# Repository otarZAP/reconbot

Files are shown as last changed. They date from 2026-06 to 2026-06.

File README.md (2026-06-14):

# 🛰️ ReconBot — a tactical two-wheeled recon drone

A small, sleek two-wheeled recon drone you and your kids can build together. A single
**ESP32-S3-CAM** streams live video to a web app and drives two
wheels through an **L298N** motor driver — a fixed forward-facing camera giving
you a live first-person view as you drive.

No app to install. The bot makes its own WiFi hotspot; your phone joins it and
opens a web page. Touch-and-hold the on-screen joystick to drive.

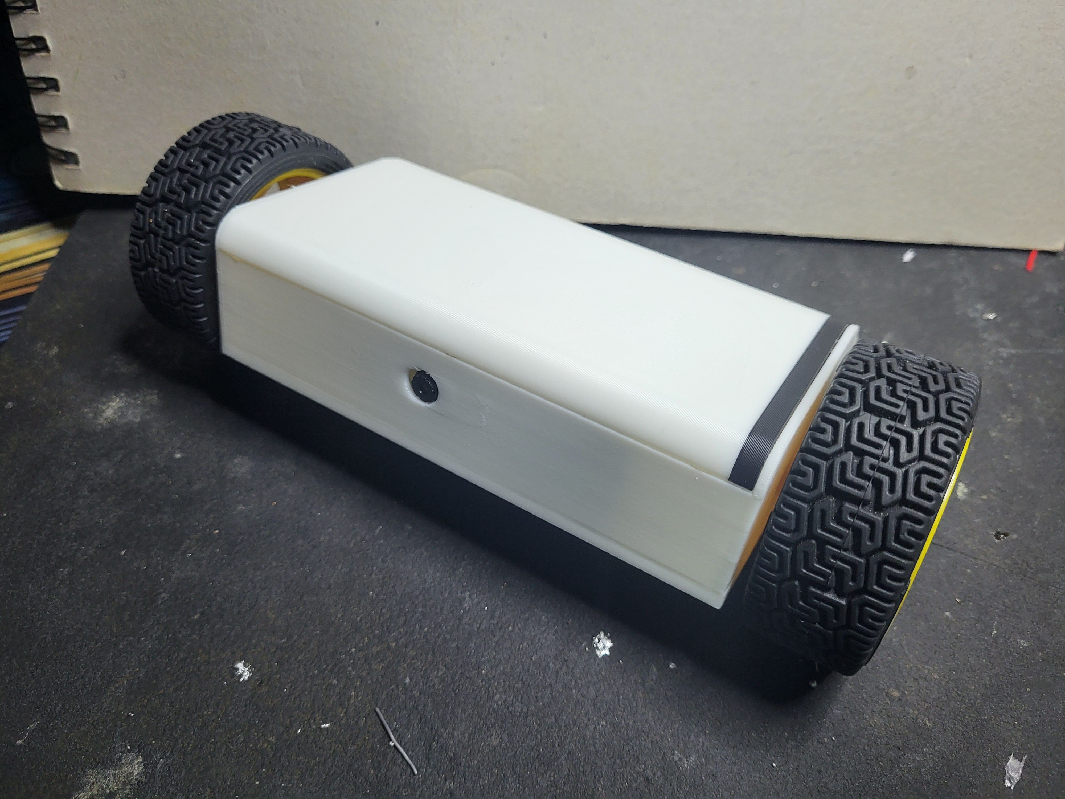
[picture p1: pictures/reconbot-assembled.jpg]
The assembled ReconBot — 3D-printed chassis and lid on car-kit wheels

*The finished drone: printed chassis + lid, riding on salvaged car-kit wheels.*

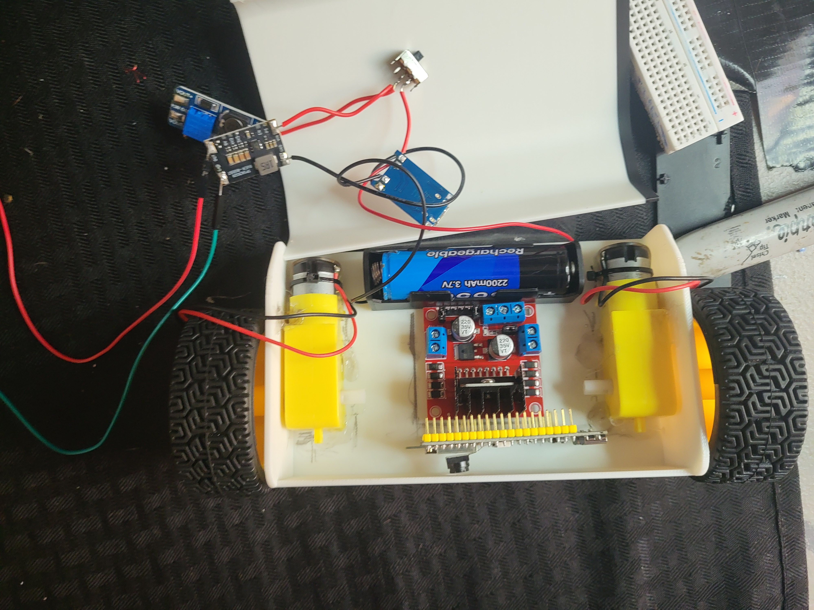
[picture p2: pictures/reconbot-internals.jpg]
Inside the chassis — motor driver, boost converter, 18650, and gear motors

*Inside: the L298N motor driver, MT3608 boost, 18650 cell, and the two gear motors.*

---

## What makes it cool

* **Coaxial-pendulum chassis** — both wheels share one axle line and the body
  hangs *below* the axle. Gravity keeps it upright, so there is **no balancing
  code to tune** — it's reliable on day one and still looks the part.
* **Live FPV camera** — a fixed forward-facing ESP32-S3-CAM streams video so you
  drive from the bot's point of view.
* **Tactical green-on-black HUD** — corner brackets, scanlines, live "LINK" status.

> We deliberately did **not** build a true Segway-style self-balancer. With
> salvaged car-kit gear motors, balancing is twitchy and frustrating to tune —
> the wrong first project. The pendulum design gives the same sleek look with
> none of the pain. See [docs/04_LEARN.md](docs/04_LEARN.md) for the physics.

---

## What you need

Most of this is common hobby-electronics stock — a lot of it can be salvaged
from an Arduino starter/car kit.

| Part | Qty | Role |
|---|---|---|
| ESP32-S3-CAM (FORIOT, OV3660) | 1 | camera + brain + WiFi + control |
| L298N dual H-bridge | 1 | drives the two wheels |
| 2× DC gear motors + wheels | 2 | drive (salvage from a toy car kit) |
| MPU-6050 IMU *(optional)* | 1 | tilt read-out on the HUD (later) |
| 18650 cell + holder | 1 | power |
| TP4056 (USB-C, protected) | 1 | charge + protect the cell |
| TPS63020 buck/boost (3.3 V) | 1 | clean power for the brain |
| MT3608 boost | 1 | 5 V for the motors |
| Rocker switch | 1 | on/off |
| Jumper wire / hookup wire | — | wiring |
| 3D-printed chassis + lid | 1 set | body (STLs included; wheels are the car-kit's) |

Full mapping + quantities: [hardware/BOM.md](hardware/BOM.md).

---

## How it's powered (quick view)

One 18650 cell, two converters — the brain and the motors are kept on
**separate power rails** so motor noise can't reset the camera (the #1 thing
that frustrates beginners).

```
18650 ─► TP4056 (charge/protect) ─► switch ─┬─ TPS63020 → 3.3V → ESP32-S3-CAM (brain)
                                            └─ MT3608   → 5.0V → L298N motor driver (muscle)
```

Full diagram + every wire: [docs/02_WIRING_GUIDE.md](docs/02_WIRING_GUIDE.md).

---

## Quick start (5 steps)

1. **Print the parts** — [hardware/3D_PRINTING.md](hardware/3D_PRINTING.md).
2. **Flash the firmware** — open [firmware/reconbot/reconbot.ino](firmware/reconbot/reconbot.ino)
   in the Arduino IDE, set the board options listed at the top of that file
   (the proven board settings — TTL port, OPI PSRAM, CDC Disabled, 115200),
   and upload.
3. **Wire it up** — follow [docs/02_WIRING_GUIDE.md](docs/02_WIRING_GUIDE.md).
4. **Connect your phone** — join WiFi **`ReconBot`** (default password
   `changeme123` — set your own in `config.h`), open Safari to
   **`http://192.168.4.1`**.
5. **Drive** — touch-hold the on-screen joystick to drive while you watch the
   live video feed.

Start to finish, step by step: [docs/01_BUILD_GUIDE.md](docs/01_BUILD_GUIDE.md).

---

## Project layout

```
reconbot/
├── README.md                  ← you are here
├── firmware/reconbot/         ← the code that runs on the ESP32-S3-CAM
│   ├── reconbot.ino           ← main program
│   ├── config.h               ← EDIT THIS: WiFi, pins, tuning
│   ├── camera_pins.h          ← camera pin map (verify vs your board)
│   └── web_index.h            ← the phone web app (HTML/CSS/JS)
├── docs/
│   ├── 01_BUILD_GUIDE.md      ← full step-by-step assembly
│   ├── 02_WIRING_GUIDE.md     ← pinouts, power tree, every connection
│   ├── 03_TROUBLESHOOTING.md  ← when something doesn't work
│   └── 04_LEARN.md            ← how it all works (the educational part)
├── hardware/
│   ├── BOM.md                 ← bill of materials
│   └── 3D_PRINTING.md         ← what to print + slicer settings
└── freecad/                   ← print-ready STLs (chassis + lid)
    ├── drone_chassis.stl
    └── drone-lid.stl
```

---

## Safety (read this with your son)

* **LiPo/Li-ion cells are not toys.** Never short the 18650, charge only on the
  TP4056, never leave charging unattended, never puncture a cell.
* **Power off (switch) before plugging in USB** to program, so two power sources
  don't fight.
* **Wheels off the ground** the first time you test motors.
* Double-check **+ and −** before switching on. Reversed power kills boards.

Have fun. 🟢

---

## License

Released under the [MIT License](LICENSE) — free to use, modify, and share.
Built as a father-and-son learning project; if you build your own, have fun
and stay safe with the battery.

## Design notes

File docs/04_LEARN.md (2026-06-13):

# 🎓 How ReconBot Works — the learning guide

The fun part: understanding *why* every piece is there. Read a section before or
after building the matching stage. Each one is short on purpose.

---

## 1. Why a "pendulum" instead of a balancing Segway?

Both have two wheels on one axle. The difference is **where the weight sits**.

* **Self-balancer (Segway):** weight is *above* the axle. That's like balancing a
  broom on your hand — it always wants to fall, so a computer must read the tilt
  (with the MPU-6050) and constantly drive the wheels to catch it. This is a
  **closed-loop control** problem solved with a **PID controller**, and it's
  genuinely hard to tune — especially with cheap gear motors that have "backlash"
  (slop in the gears) and a delay before they respond.

* **Pendulum (what we built):** weight hangs *below* the axle. That's like a
  swing or a pendulum — gravity *pulls it upright on its own*. No sensor, no
  control loop, no tuning. It's **passively stable**. It still has that sleek
  two-wheeled drone look because the wheels and body shape are the same.

> Engineering lesson: the best way to solve a hard control problem is often to
> **redesign so you don't need control at all**. Moving the battery low turned a
> PID-tuning nightmare into a part that just works. Keep the self-balancer in
> your back pocket as a *future* project once the motors and code are familiar.

The MPU-6050 still earns a spot later: we can *read* the tilt and show it on the
HUD for telemetry — using the sensor without depending on it to stay upright.

---

## 2. How the motors are controlled — H-bridge + PWM

A DC motor has two terminals. Apply voltage one way → spins forward; flip the
voltage → spins backward. To flip voltage under software control we use an
**H-bridge** — four electronic switches in an "H" shape around the motor. The
**L298N** has two H-bridges (one per motor).

* The two **direction pins** (IN1/IN2 for the left motor) pick which way current
  flows → which way the wheel turns.
* The **enable pin** (ENA) turns the bridge on/off. We don't just turn it on — we
  flick it on-and-off *thousands of times a second*. The fraction of time it's
  on is the **duty cycle**. 100% on = full speed, 50% = roughly half speed. This
  trick is **PWM (Pulse-Width Modulation)**, and it's how almost everything
  controls power smoothly: motor speed, LED brightness, even class-D audio.

In the code, `ledcWrite(pin, duty)` sets the duty (0–255). The ESP32 has
dedicated **LEDC** hardware that generates the PWM so the main program is free
to do other things (like stream video).

> Detail worth knowing: the camera *also* uses an LEDC channel for its clock.
> That's why the code uses `ledcAttachChannel(...)` to put the motor PWM on
> *different* channels — two parts sharing one hardware resource would fight.

---

## 3. How video gets to your phone — MJPEG

Video sounds complicated, but ours is simple: the camera takes a **JPEG photo**,
sends it, takes another, sends it… ~20–30 times a second. Your eye blends them
into motion. That stream of JPEGs over one HTTP connection is called **MJPEG**
(Motion JPEG). The browser's `<img>` tag knows how to keep showing the newest
frame.

It's not as efficient as "real" video (H.264), but it's **dead simple and
low-latency**, which is perfect for driving a robot where you want to see *now*,
not a smooth-but-delayed picture.

---

## 4. How the controls reach the bot — a tiny web server

The ESP32 runs a small **web server**. Two jobs, on two ports:

* **Port 80** serves the HUD web page and listens for commands like
  `/control?joy=30,-80` (steer + drive) or `/control?cmd=S` (stop).
* **Port 81** serves the MJPEG video, so a slow video frame never blocks a
  control command.

As you move the on-screen joystick, the page sends `joy=x,y` (turn, forward).
Let go and it sends `cmd=S` (stop). That's the whole protocol — plain text in a
URL. You could literally type one into a browser to drive the bot.

> No app store, no install: the bot *is* a web server, and the browser already on
> the iPhone is the client. That's the same idea that runs the whole internet.

---

## 5. The failsafe — why the bot stops itself

What if you walk out of WiFi range, or close the app, while driving? The bot
would keep going. So the page sends a quiet "ping" every 0.4 s, and the firmware
remembers the time of the **last message**. In `loop()`, if more than
`FAILSAFE_MS` (0.7 s) passes with no message, it stops the motors.

> This is a **watchdog / deadman switch** — a core safety pattern in robotics,
> cars, and industrial machines: "if I stop hearing from the controller, assume
> the worst and go safe."

---

## 6. Why two separate power supplies?

Motors are *electrically loud*. When they start, they yank current and make the
voltage dip and spike. A sensitive brain (ESP32 + camera + WiFi radio) sharing
that same wire will **brown out and reset** — the single most common beginner
frustration with ESP32-CAM robots.

So we split power into two **rails**:

* **TPS63020 → 3.3 V → brain.** It's a **buck-boost** converter: it can step
  voltage *down or up*. Even when the battery sags under motor load, it *boosts*
  back up to a steady 3.3 V. The brain never notices the motors.
* **MT3608 → 5 V → motors.** All the noisy stuff lives here.

They only meet at the battery and at **common ground**. Clean brain, happy bot.

> Why not a 2-cell pack into the TPS63020 for more motor power? Because that part
> accepts **max 5.5 V in** — a single Li-ion cell only. Datasheets matter: one
> overlooked number can release the magic smoke. 🔌💨

---

## 7. The whole signal flow, one picture

```
   your thumb            iPhone (Safari)             ESP32-S3-CAM                 the world
  ───────────  touch  ─────────────────  WiFi  ──────────────────────────────  ──────────
   hold ▲      ─────►  send /control?cmd=F ───►  web server (port 80)
                                                    │
                                                    ├─► set motor pins + PWM ─►  L298N ─► wheels turn
   camera   ◄──────── <img> shows JPEGs ◄───── MJPEG stream (port 81) ◄── camera takes photos
                          (every 0.4s: ping ───► resets the failsafe timer)
```

That's the entire robot. Five small ideas — H-bridge, PWM, MJPEG, a web server,
and a watchdog — wired together. Once these click, you can build almost any
connected robot. 🟢

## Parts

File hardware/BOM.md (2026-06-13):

# 📦 Bill of Materials

Most of these are common hobby-electronics parts, and several can be salvaged
from an Arduino starter/car kit. You shouldn't need anything exotic.

## Core build (required)

| # | Part | Qty | Role |
|---|---|----:|---|
| 1 | **ESP32-S3-CAM (FORIOT, OV3660, N16R8)** | 1 | Camera + brain + WiFi + control |
| 2 | **L298N dual H-bridge module** | 1 | Drives both wheels |
| 3 | **DC gear motors + wheels** | 2 | Drive — salvage from a toy/Arduino car kit |
| 4 | **18650 Li-ion cell** | 1 | Main battery |
| 5 | **18650 holder (single, wire leads)** | 1 | Holds the cell |
| 6 | **TP4056 Type-C charger w/ protection** | 1 | Charge + protect the cell |
| 7 | **TPS63020 / XL63020 buck-boost (3.3 V)** | 1 | Clean 3.3 V for the brain |
| 8 | **MT3608 boost converter** | 1 | 5 V for the motors |
| 9 | **Rocker switch (SPST)** | 1 | Master on/off |
| 10 | **Hookup wire / jumper wires** | — | Wiring |
| 11 | **Heatshrink, solder** | — | Tidy, durable joints |
| 12 | **3D-printed chassis + lid** | 1 set | Body + top cover (STLs included; wheels come from the car kit) |

> **Battery note:** use a good **18650** cell for the bot. Avoid tiny 1S LiPos
> (e.g. 450 mAh) — they're too small to drive the motors well. Only charge the
> cell on the TP4056, and never leave it charging unattended.

## Optional / later add-ons

| Part | Adds |
|---|---|
| **MPU-6050 IMU** | Live tilt/heading on the HUD (`USE_IMU 1`) |
| **DFPlayer Mini + 3 W speaker** | Startup chirp / "drone deployed" voice |
| **SSD1306 OLED 0.96"** | Tiny on-board status display |
| **LED** | Headlight on a spare GPIO |
| **NEO-6M GPS** | Outdoor position logging |
| **Spare ESP32-S3 devkit (e.g. XIAO ESP32-S3)** | Second brain / experiments |

## Tools

Soldering iron + solder + heatshrink · flush cutters · digital calipers ·
multimeter · breadboard + jumpers (for bench-testing power) ·
a 3D printer + PLA/PETG filament.

---

### A note on quantities
This is a forgiving first build. The ESP32-S3-CAM and the support parts are
cheap, so it's worth having a spare or two on hand — you can build more than one
drone and not stress about releasing a little magic smoke while you learn.

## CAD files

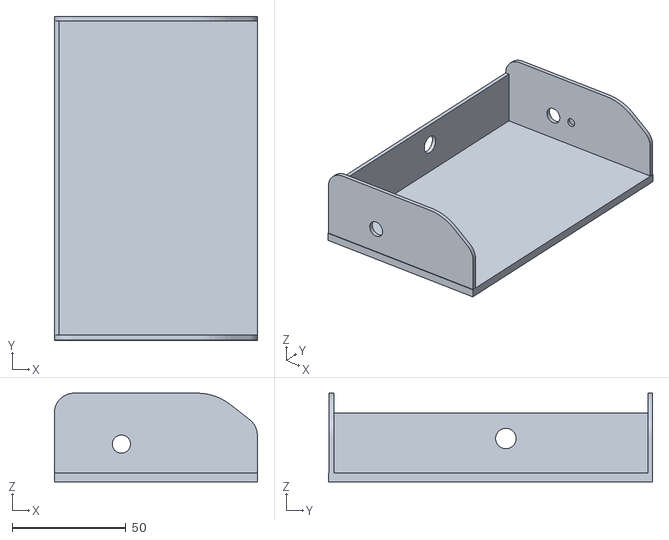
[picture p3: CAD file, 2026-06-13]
freecad/drone_chassis.stl
89.6 x 142.7 x 39.1

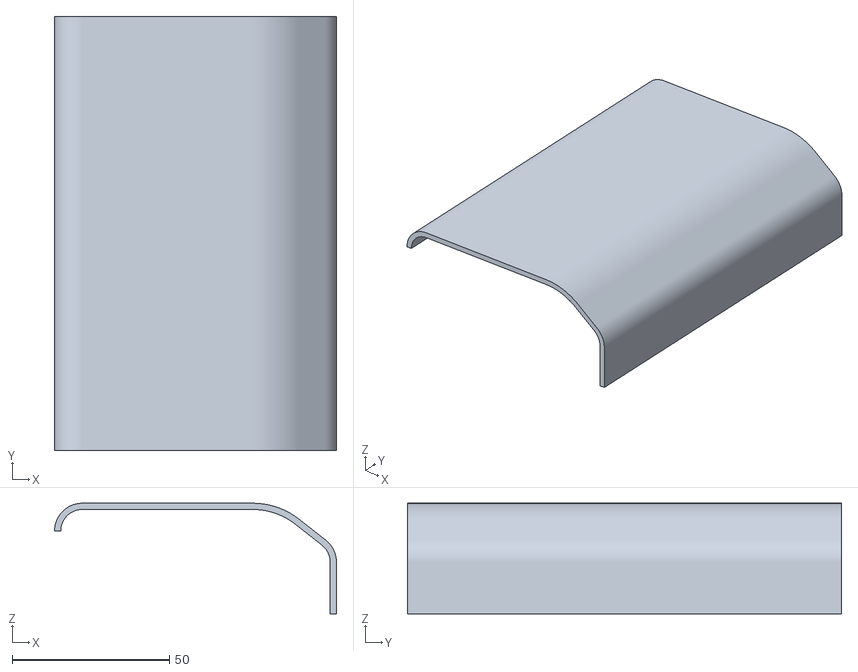
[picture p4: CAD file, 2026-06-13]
freecad/drone-lid.stl
89.6 x 138.0 x 35.1

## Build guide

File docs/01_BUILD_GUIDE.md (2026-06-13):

# 🛠️ ReconBot Build Guide

A staged build. Each stage **ends in a test** — don't move on until the test
passes. This is the secret to "smooth sailing": you never debug ten things at
once, only the one thing you just added.

**Time:** ~a weekend, split into sessions. Great pace for building with a teen.

**Tools you have:** soldering iron + heatshrink, flush cutters, calipers,
multimeter (from the ELEGOO kit / power supply), the P1S printer.

---

## Stage 0 — Set up the computer (30 min)

1. Install the **Arduino IDE 2.x** (free, arduino.cc).
2. Add ESP32 support: **File ▸ Preferences ▸ Additional Boards Manager URLs**,
   paste:
   `https://raw.githubusercontent.com/espressif/arduino-esp32/gh-pages/package_esp32_index.json`
3. **Tools ▸ Board ▸ Boards Manager**, search **esp32**, install **"esp32" by
   Espressif Systems** (v3.0 or newer).
4. Plug the ESP32-S3-CAM into the computer using the **USB-C port labelled
   "TTL"** (the CH340C port). The **OTG** port is *not* for flashing. A COM port
   should appear under **Tools ▸ Port**.

✅ **Test:** the board appears as a COM port. (No code yet.)

> If you've flashed an ESP32-S3-CAM before, the BOOT/RST dance below will be
> familiar — same procedure applies here.

---

## Stage 1 — Flash the ReconBot firmware (15 min)

The camera pin map is **already confirmed** (taken from the FORIOT board's
silkscreen pinout and verified on hardware), so we skip straight to the firmware.

1. Open [`firmware/reconbot/reconbot.ino`](../firmware/reconbot/reconbot.ino).
   The folder also has `config.h`, `camera_pins.h`, `web_index.h` — keep all
   four together; the IDE opens them as tabs.
2. In **`config.h`**, set your hotspot password (`AP_PASS`) to something you'll
   remember. Leave everything else at defaults for now.
3. Set **Tools** to these proven settings:
   * Board: **ESP32S3 Dev Module**
   * PSRAM: **OPI PSRAM**  ← mandatory; camera won't init without it
   * Flash Size: **16MB (128Mb)**
   * Partition Scheme: **16M Flash (3MB APP/9.9MB FATFS)** (or **Huge APP**)
   * USB CDC On Boot: **Disabled**
   * Upload Speed: **115200**  (lower = more reliable on the CH340)
4. **Enter download mode:** hold **BOOT**, tap **RST**,
   release **BOOT**, then click **Upload** immediately.
5. Open **Tools ▸ Serial Monitor** at **115200**. You should see:
   `AP up. Join WiFi 'ReconBot', then open http://192.168.4.1`.
6. On your iPhone: **Settings ▸ WiFi ▸ ReconBot**, enter the password. Then open
   **Safari ▸ `http://192.168.4.1`**.

✅ **Test:** the green tactical HUD loads on your phone with live video. (No
motors yet — the D-pad does nothing because the L298N isn't wired. That's fine.)

> Upload won't connect? It's almost always the wrong USB-C port (use TTL), the
> upload speed, or the BOOT/RST timing — see
> [03_TROUBLESHOOTING.md](03_TROUBLESHOOTING.md). iPhone may warn "no internet"
> on the ReconBot network — expected; stay connected anyway. WiFi is 2.4 GHz.

> **Optional confidence check:** if you'd rather prove the camera before our
> code, flash **File ▸ Examples ▸ ESP32 ▸ Camera ▸ CameraWebServer** (model
> `CAMERA_MODEL_ESP32S3_EYE`) first — but since the pin map already matches your
> working cameras, you can skip this.

---

## Stage 2 — Print the parts (print while you build)

Start these prints now; they run in the background. Settings + the sleek,
compact pendulum design are in [hardware/3D_PRINTING.md](../hardware/3D_PRINTING.md).

You'll print just two parts — the included STLs: the **chassis** (the main body;
it holds the ESP32 + L298N + battery, mounts the motors, and *hangs below the
axle*) and a **lid** that closes the top. The **wheels come from the car kit**,
not the printer.

✅ **Test:** the chassis comes off the plate clean; the ESP32 and L298N sit in
their slots and the 18650 drops into the bottom.

---

## Stage 3 — Build & test the power tree (45 min)

Follow [02_WIRING_GUIDE.md](02_WIRING_GUIDE.md) §1. Build power **on the
breadboard first**, not soldered to the bot.

1. 18650 → TP4056 (**B+/B−**). Bot power comes from TP4056 **OUT+/OUT−**.
2. Add the **switch** in the OUT+ line.
3. Wire the **TPS63020** input to the switched rail. Switch on. Measure its
   output: **3.3 V**. Switch off.
4. Wire the **MT3608** input to the switched rail. Switch on. Adjust its pot to
   **5.0 V** on the output. Switch off.

✅ **Test:** multimeter reads 3.3 V and 5.0 V on the two rails, and nothing gets
warm. Don't connect any boards until both rails are confirmed.

---

## Stage 4 — Wire & test the motors (45 min)

1. **Switch off / USB unplugged.** Wire ESP32 → L298N per
   [02_WIRING_GUIDE.md](02_WIRING_GUIDE.md) §2 (the 6 signal pins + GND).
2. Remove the **ENA/ENB jumpers** and the **+5V regulator jumper** on the L298N.
3. Feed L298N **+12V (VS)** and **+5V** from the 5 V rail; connect **GND**.
4. Connect the two motors to OUT1/2 and OUT3/4. **Keep wheels off the ground.**
5. Power the brain from the 3.3 V rail (3V3 + GND). Switch on.
6. Connect the phone, open the HUD, and press the D-pad.

✅ **Test:** push the joystick forward and both wheels spin the same way (the way
that would move the bot forward). Push left/right to check steering. The further
you push the stick, the faster it goes — there's no separate speed slider.

* A wheel spins backward? Swap that motor's two output wires, **or** set
  `INVERT_LEFT`/`INVERT_RIGHT` in `config.h` and re-upload.
* Camera resets when motors start? Your rails aren't separate — recheck that the
  brain is on the **TPS63020** rail, not the motor rail. (See Troubleshooting.)

> Notice the **failsafe**: let go of the D-pad and the wheels stop. Close the
> app and within ~0.7 s the bot stops itself.

---

## Stage 5 — Mechanical assembly (the pendulum chassis) (1–2 hr)

This is what gives it its distinctive look. The key idea: **the two motors mount on a
single axle line, and the chassis hangs below them.** Low weight = naturally
upright.

1. **Mount the motors** in the chassis so both output shafts are **coaxial**
   (pointing left and right along one straight line).
2. **Press the car-kit wheels** onto the shafts.
3. The **chassis hangs below** the shaft line so its mass sits *below* the axle.
   Put the **heaviest item (the 18650) at the very bottom** — the lower the
   battery, the more stable and upright it sits.
4. **Mount the camera** on the front of the chassis, facing forward. It's
   **fixed** (no tilt) — aim it roughly level so you can see where you're driving.
5. Route wires neatly and secure them with a little tape or zip-ties, then
   **clip the lid on** top.

✅ **Test (the magic moment):** set it on the floor, hands off. It should sit
upright on its two wheels, body hanging below the axle. A gentle
nudge and it rocks back upright.

> If it won't stay upright: move the battery **lower**, and make sure the body's
> center of mass is **below** the axle, not level with it. If it spins around the
> axle hard when you hit Forward, push the stick more gently, lower
> **`DEFAULT_SPEED`** in `config.h`, and/or raise **`JOY_EXPO`** for a softer
> throttle — gentle starts keep the body from swinging.

---

## Stage 6 — First drive & tuning (ongoing fun)

* Start **gently**. The pendulum body will bob when you accelerate — that's
  authentic and expected. Smooth, gentle throttle looks best.
* Tune the *feel* in `config.h`: `DEFAULT_SPEED`, `TURN_SPEED_SCALE`,
  `JOY_EXPO`. Re-upload to try changes.

### Ideas to grow it (great next lessons)

* Turn on the **MPU-6050** (`USE_IMU 1`) and show live tilt on the HUD.
* Add a **headlight LED** on a spare GPIO with a button on the HUD.
* Add sound with a **DFPlayer Mini + speaker** (you have both) — a startup chirp
  or "drone deployed" voice line.
* Try **`WIFI_MODE_STA`** so it joins home WiFi and you drive from any room.

See the physics and the "why" behind every choice in
[04_LEARN.md](04_LEARN.md).

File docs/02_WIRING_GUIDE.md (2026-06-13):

# 🔌 ReconBot Wiring Guide

Every wire, every pin. Wire with the **battery removed and the power switch
OFF**. Work slowly and check each connection against the tables before you
apply power.

> **Camera pins + flash settings are confirmed** from the FORIOT
> ESP32-S3-CAM's silkscreen pinout — no guessing there. The **motor GPIOs**
> below are a sound default chosen to dodge the camera, flash/PSRAM, USB,
> serial, and boot pins. If one isn't broken out on a header pad on your board,
> pick another free pin (good spares: 21, 48, 1, 2) and change it in
> [`config.h`](../firmware/reconbot/config.h) — that's the only place to edit.
> Check your board's silkscreen / pinout diagram to confirm which pads are
> broken out.

---

## 1. The power tree (build this first, test it before anything else)

One 18650 cell. The brain and the muscle live on **separate rails** on purpose:
motors create electrical noise and voltage dips, and if the camera shared that
rail it would constantly reset. The TPS63020 also *boosts* — so even when the
cell sags under motor load, the brain still gets a steady 3.3 V.

```
                       ┌─────────────────────────────────────────────┐
                       │                                             │
  [18650 +]──► TP4056 OUT+ ──► [SWITCH] ──┬──► TPS63020 IN+ ──► OUT 3.3V ──► ESP32-S3-CAM  3V3
  [18650 -]──► TP4056 OUT- ───────────────┤    TPS63020 IN- ──► OUT GND  ──► ESP32-S3-CAM  GND
                                          │
                                          ├──► MT3608 IN+ ──► OUT 5V ──┬──► L298N  +12V (VS)
                                          │    MT3608 IN- ──► OUT GND  └──► L298N  +5V  (logic, jumper OFF)
                                          │
                                          └────────────────── COMMON GROUND ──────────────────┐
                                                                                               │
   ALL grounds tie together:  18650- / TP4056 OUT- / TPS63020 GND / MT3608 GND /              │
   L298N GND / ESP32 GND ──────────────────────────────────────────────────────────────────────┘
```

**Set the converter voltages with a multimeter BEFORE connecting any board:**

* **TP4056** — battery goes on **B+ / B−**; the bot draws from **OUT+ / OUT−**.
  Charge any time via the TP4056's USB-C. (Protected version — good.)
* **TPS63020 (XL63020)** — fixed **3.3 V** out. Confirm it reads ~3.3 V.
* **MT3608** — turn its trim-pot until the output reads **5.0 V**. Do this with
  nothing connected to the output yet. (Want peppier motors later? 6 V is fine.)

> ⚠️ **Never feed more than 5.5 V into the TPS63020** — it's a single-cell part.
> That's why we power the brain straight from the one cell, not from a 2-cell pack.

> ⚠️ **Power switch OFF before connecting USB** to the ESP32 for programming.
> Otherwise USB-5V and the 3.3 V rail both try to power the board and fight.

---

## 2. ESP32-S3-CAM → L298N (motor driver)

The ESP32 sends 6 logic signals to the L298N: 2 direction + 1 speed (PWM) per motor.

| ESP32-S3 pin | → L298N pin | Meaning |
|---|---|---|
| GPIO **42** | IN1 | Left motor direction A |
| GPIO **41** | IN2 | Left motor direction B |
| GPIO **40** | ENA | Left motor speed (PWM) |
| GPIO **39** | IN3 | Right motor direction A |
| GPIO **38** | IN4 | Right motor direction B |
| GPIO **47** | ENB | Right motor speed (PWM) |
| **GND** | GND | shared ground (also in the power tree) |

> **ENA/ENB jumpers:** the L298N ships with little jumpers on ENA/ENB that force
> full speed. **Remove both jumpers** so our PWM speed control works.

> **The "+5V logic" jumper:** there's a jumper near the +5V terminal that
> enables the on-board 5 V regulator. Since we feed 5 V in from the MT3608,
> **remove that jumper** and feed the **+5V** terminal from the 5 V rail instead.

> **microSD note:** GPIO 38/39/40 are the FORIOT board's microSD slot pins
> (confirmed from the FORIOT pinout). We borrow them for motors, so
> **leave the microSD slot empty** for this build.

### L298N → motors

| L298N output | → wire | Motor |
|---|---|---|
| OUT1 / OUT2 | the two leads | **Left** gear motor |
| OUT3 / OUT4 | the two leads | **Right** gear motor |

Polarity doesn't matter yet — if a wheel spins the wrong way during testing,
either swap that motor's two wires **or** flip `INVERT_LEFT` / `INVERT_RIGHT`
in `config.h`. No re-soldering needed.

---

## 3. (Optional, later) MPU-6050 IMU

Skip this for the first build. When you want a live tilt/heading read-out on the
HUD, set `USE_IMU 1` in `config.h` and wire:

| MPU-6050 | → ESP32-S3 |
|---|---|
| VCC | 3.3 V |
| GND | GND |
| SDA | GPIO **1** |
| SCL | GPIO **2** |

(This is a *second* I²C bus, separate from the camera's internal one.)

---

## 4. Pre-power checklist

Before the very first switch-on:

- [ ] **+ and −** correct at every module (look twice).
- [ ] TPS63020 output reads **3.3 V**, MT3608 output reads **5.0 V** (measured, loaded later).
- [ ] **All grounds connected together** (brain, motors, converters, battery).
- [ ] ENA/ENB jumpers **removed**; L298N +5V regulator jumper **removed**.
- [ ] microSD slot **empty**.
- [ ] Wheels **off the ground**.
- [ ] USB **unplugged** (or switch off) so power sources don't fight.

First switch-on: the ESP32's small LED should light, and within ~5 s the
`ReconBot` WiFi network should appear on your phone. If anything smells hot or a
chip gets warm fast — **switch off immediately** and recheck polarity.

---

## Pin reference (one-page summary)

```
ESP32-S3-CAM
 ├─ 3V3  ◄── TPS63020 3.3V        (brain power)
 ├─ GND  ──  common ground
 ├─ G42 ──► L298N IN1   (L dir)
 ├─ G41 ──► L298N IN2   (L dir)
 ├─ G40 ──► L298N ENA   (L speed/PWM)
 ├─ G39 ──► L298N IN3   (R dir)
 ├─ G38 ──► L298N IN4   (R dir)
 └─ G47 ──► L298N ENB   (R speed/PWM)

L298N
 ├─ +12V (VS) ◄── 5V rail (MT3608)
 ├─ +5V       ◄── 5V rail (MT3608)   [regulator jumper OFF]
 ├─ GND       ──  common ground
 ├─ OUT1/OUT2 ──► Left motor
 └─ OUT3/OUT4 ──► Right motor
```

Next: assemble it all in [01_BUILD_GUIDE.md](01_BUILD_GUIDE.md).

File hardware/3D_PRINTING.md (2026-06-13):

# 🖨️ 3D Printing Guide

Two ready-to-print parts are included as STLs — no CAD needed to build:

* [`freecad/drone_chassis.stl`](../freecad/drone_chassis.stl) — the main body
* [`freecad/drone-lid.stl`](../freecad/drone-lid.stl) — the top cover

Drop them into your slicer and print. (The editable FreeCAD source isn't bundled
in this repo — export fresh STLs from your own model if you want to change the
geometry.)

> The **wheels are not printed** — they come from the salvaged car kit (see the
> [BOM](BOM.md)). The printed parts are just the body and its lid.

---

## What you'll print

| Part | File | Qty | Notes |
|---|---|----:|---|
| **Chassis** | `drone_chassis.stl` | 1 | Main body — holds the motors, electronics, and 18650; hangs below the axle so the mass sits low. |
| **Lid** | `drone-lid.stl` | 1 | Closes the top of the chassis and protects the electronics. |

Total filament: small — a couple of hours, well under one spool.

---

## Step 1 — Slice & print (Bambu Studio / any slicer)

| Setting | Chassis & lid |
|---|---|
| Material | **PLA** (PETG if you want it tougher) |
| Layer height | 0.20 mm |
| Walls | 3 |
| Infill | 20–30 % |
| Supports | **Yes** for overhangs / the front camera window |
| Brim | optional (helps on small contact areas) |

> If your salvaged motors or boards are a different size than the model expects,
> the parts may not fit. In that case you'll need to tweak and re-export from
> your own CAD — start press-fit clearances around 0.25 mm (too tight → raise
> toward 0.35 mm; too loose → lower it).

## Step 2 — Test the fits before assembly

* Motors, the ESP32-S3-CAM, the L298N, and the 18650 should all sit in the
  **chassis** with the **battery lowest** (that low mass is what keeps the
  pendulum upright).
* The camera fixes to the front of the chassis, facing forward — see the
  [build guide](../docs/01_BUILD_GUIDE.md).
* The **lid** should close over the top without crushing wires. Route cables
  first, then clip it on.
* **Car-kit wheels:** for more grip on smooth floors, wrap each tyre with a
  slice of silicone tape or a wide rubber band.

---

## Design intent (so you can restyle it)

The whole point of the shape is **low center of mass**: the chassis hangs
*below* the axle and the heavy 18650 lives at the bottom. That's what makes the
pendulum sit upright with no balancing code (see
[../docs/04_LEARN.md](../docs/04_LEARN.md) §1).

Want it to look more rugged/tactical? Things you can change in your own model:

* Add a faceted/angular shell around the body.
* Print a thin top "cage" so it reads as a rugged little recon unit.

Keep the **mass low and centered** and you can style the rest however you like.

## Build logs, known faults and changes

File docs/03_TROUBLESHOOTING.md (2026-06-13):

# 🚑 ReconBot Troubleshooting

Work top-down: most problems are power or pins. Use the multimeter — guessing
wastes time.

---

## Uploading / board

**No COM port appears.**
* Use the **TTL** USB-C port (CH340C), **not** the OTG port.
* Try a different USB **cable** (many are charge-only with no data wires).

**Upload fails: "Failed to connect… No serial data received."** In order of
likelihood:
1. **Wrong port.** Use TTL, not OTG.
2. **Upload Speed too high.** Drop to **115200**.
3. **Bad cable.** Must be a data cable. Swap and test.
4. **Wrong button sequence.** Hold **BOOT** → tap **RST** → release **BOOT** →
   click Upload. Don't touch the buttons again.
5. **Battery rail on.** The power switch must be **OFF** while programming.
6. **Flaky BOOT button bypass:** short **GPIO0 to GND** with a wire while
   tapping RST, then release the wire.
7. **Dead BOOT button** (worked once, never again): the board is mechanically
   faulty — swap it. (You can't brick the chip; the ROM bootloader is permanent.)

**Compile error about `ledcAttach` / camera functions.**
* You're on an old core. Update **esp32 by Espressif** to **v3.0+** in Boards
  Manager. The v3.x LEDC API (`ledcAttach`) and these camera calls need it.

---

## Camera

**`CAMERA INIT FAILED 0x…` on the serial monitor.**
* **PSRAM** must be set to **OPI PSRAM** (Tools menu). This is almost always the
  cause — the camera won't init without OPI PSRAM.
* The pin map in `camera_pins.h` is taken from the FORIOT silkscreen pinout, so
  it usually isn't the pins. It's the PSRAM setting or a bad board.

**Video is upside-down or mirrored.**
* In `reconbot.ino`, in `cameraBegin()`, change `set_vflip` / `set_hmirror`
  (1 ↔ 0).

**HUD loads but video box stays black / "connecting".**
* The video lives on **port 81**. Some networks block it, but on the bot's own
  hotspot it's fine. Reload the page. The HUD auto-retries every second.
* Camera init may have failed — check the serial monitor (the bot still serves
  the page and drives even if the camera didn't start).

---

## Power (most "weird" problems live here)

**Camera/brain resets every time the motors move.**
* Classic shared-rail noise. The brain **must** be on the **TPS63020 3.3 V**
  rail, the motors on the **MT3608 5 V** rail — fed straight from the cell, not
  from each other. Recheck the power tree.
* Make sure **all grounds are tied together**.

**Nothing powers on.**
* Is the **switch** on? Battery charged? Measure TP4056 **OUT+** to **OUT−** —
  should be ~3.0–4.2 V.
* Measure the **two converter outputs** (3.3 V and 5.0 V). If a converter reads
  0 V, recheck its IN+ / IN− and that it's getting battery voltage.

**A module or chip gets hot fast.**
* **Switch off immediately.** Almost always reversed **+/−** on that module.
  Recheck polarity before powering again.

**TPS63020 died / outputs garbage.**
* It's a single-cell part (**max 5.5 V in**). If you fed it a 2-cell pack it's
  damaged. Use one of your spares and feed it from the single cell only.

---

## Motors

**D-pad does nothing.**
* ENA/ENB **jumpers removed**? With them on, sometimes; with our PWM they must be
  off — but also confirm the 6 signal wires match the table in the Wiring Guide.
* Is the L298N getting **+12V (VS)** *and* **+5V** *and* **GND**?
* Are the motors connected to OUT1/2 and OUT3/4?

**One wheel spins the wrong way.**
* Swap that motor's two output wires, **or** flip `INVERT_LEFT` /
  `INVERT_RIGHT` in `config.h` and re-upload.

**Motors weak / stall.**
* Raise the **MT3608** output toward 6 V (re-measure).
* Raise `DEFAULT_SPEED` in `config.h`.
* Cheap gear motors have a minimum speed — values below ~80 may just buzz; the
  HUD slider already starts at 80.

**Both wheels run only at full speed regardless of slider.**
* The **ENA/ENB jumpers are still on**. Remove them.

---

## Driving feel (pendulum chassis)

**Body swings hard / spins around the axle on launch.**
* Ease off the throttle (push the joystick less) or lower **`DEFAULT_SPEED`** in
  `config.h` — gentle throttle keeps the body from lurching.
* Move the **battery lower** in the chassis (lower center of mass = steadier).

**Won't stay upright at rest.**
* Center of mass must be **below** the axle. Add the battery at the very bottom
  of the pod; remove top-heavy items.

---

## Connection

**Phone can't find the `ReconBot` WiFi.**
* Give it ~5 s after power-on. Check the serial monitor printed `AP up`.
* Forget/re-join the network on the phone.

**Connected but `192.168.4.1` won't load.**
* Make sure you're on the **ReconBot** network (not your home WiFi). Ignore the
  "no internet" warning — that's normal.
* Type the full `http://192.168.4.1` (not https).

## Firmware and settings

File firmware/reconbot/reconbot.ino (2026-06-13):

// ===========================================================================
//  ReconBot  —  ESP32-S3-CAM recon drone firmware
// ---------------------------------------------------------------------------
//  ONE ESP32-S3-CAM does everything:
//    * streams live video to your phone (MJPEG, port 81)
//    * serves the control web app (port 80)
//    * drives two motors through an L298N (virtual-joystick steering)
//    * smooth soft-start ramping so starts/stops/turns aren't jerky
//    * drives at 640x480; HD button bumps resolution as the signal allows
//    * stops itself if the phone disconnects (failsafe)
//
//  Edit pins / WiFi / tuning in  config.h  — not here.
//  Camera pins live in  camera_pins.h.  Web app lives in  web_index.h.
//
//  Board settings in Arduino IDE (Tools menu) — these are the SAME settings
//  proven on the FORIOT ESP32-S3-CAM (N16R8):
//    Board:            "ESP32S3 Dev Module"
//    PSRAM:            "OPI PSRAM"        <-- MANDATORY; camera won't init without it
//    Flash Size:       "16MB (128Mb)"
//    Partition Scheme: "16M Flash (3MB APP/9.9MB FATFS)"  (or "Huge APP")
//    USB CDC On Boot:  "Disabled"         <-- we use UART0 over the CH340 "TTL" port
//    Upload Speed:     "115200"           <-- lower = more reliable on the CH340
//  Plug into the USB-C port labelled TTL (CH340C), NOT the OTG port.
//  To upload: hold BOOT, tap RST, release BOOT, then click Upload.
//  Needs the ESP32 board package v3.x (Boards Manager -> "esp32" by Espressif).
//  No extra libraries to install — everything used here ships with the core.
// ===========================================================================
#include "esp_camera.h"
#include <WiFi.h>
#include "esp_wifi.h"          // for the connected-phone signal strength (RSSI)
#include "esp_http_server.h"
#include "esp_timer.h"

#include "config.h"
#include "camera_pins.h"
#include "web_index.h"

#if USE_IMU
  #include <Wire.h>
#endif

httpd_handle_t control_httpd = NULL;   // port 80: web app + commands
httpd_handle_t stream_httpd  = NULL;   // port 81: video

volatile uint32_t g_lastCmdMs = 0;     // when we last heard from the phone
int  g_speed   = DEFAULT_SPEED;        // 0..255 (top speed; joystick scales within)
int  g_trim    = 0;                    // -100..100 steering trim (drive-straight tuning)
bool g_moving  = false;                // are we commanding any wheel movement?

// Virtual-joystick input, normalised to -100..100 (x = turn, y = forward).
int  g_jx = 0, g_jy = 0;

// Soft-start ramping: we move the CURRENT wheel duties toward the TARGET duties
// a little each loop tick (signed, -255..255; sign = direction).
int  g_tgtL = 0, g_tgtR = 0;
int  g_curL = 0, g_curR = 0;

volatile bool g_dancing = false;       // true while the DANCE routine owns the motors

// Camera resolution state (see config.h section 6)
bool        g_psram    = false;              // true if PSRAM present -> hi-res allowed
bool        g_hires    = false;              // HD button state
framesize_t g_curFrame = DRIVE_FRAMESIZE;    // resolution the sensor is at right now

// ---------------------------------------------------------------------------
//  MOTORS
// ---------------------------------------------------------------------------
void motorsBegin() {
  pinMode(MOTOR_A_IN1, OUTPUT);
  pinMode(MOTOR_A_IN2, OUTPUT);
  pinMode(MOTOR_B_IN3, OUTPUT);
  pinMode(MOTOR_B_IN4, OUTPUT);
  // Hardware PWM on the enable pins (auto-allocated from the bottom timers;
  // the camera sits on the top timer/channel so there's no clash).
  ledcAttach(MOTOR_A_PWM, PWM_FREQ, PWM_RES_BITS);
  ledcAttach(MOTOR_B_PWM, PWM_FREQ, PWM_RES_BITS);
  ledcWrite(MOTOR_A_PWM, 0);
  ledcWrite(MOTOR_B_PWM, 0);
}

// dir: +1 forward, -1 backward, 0 coast.  duty: 0..255
void setLeft(int dir, int duty) {
  if (INVERT_LEFT) dir = -dir;
  digitalWrite(MOTOR_A_IN1, dir > 0);
  digitalWrite(MOTOR_A_IN2, dir < 0);
  ledcWrite(MOTOR_A_PWM, dir == 0 ? 0 : duty);
}
void setRight(int dir, int duty) {
  if (INVERT_RIGHT) dir = -dir;
  digitalWrite(MOTOR_B_IN3, dir > 0);
  digitalWrite(MOTOR_B_IN4, dir < 0);
  ledcWrite(MOTOR_B_PWM, dir == 0 ? 0 : duty);
}

// Push a SIGNED duty (-255..255) to one wheel: sign picks direction, |value| the speed.
void applyWheel(bool left, int v) {
  int dir  = (v > 0) ? 1 : (v < 0 ? -1 : 0);
  int duty = abs(v);
  if (left) setLeft(dir, duty); else setRight(dir, duty);
}

// Hard stop + full reset so a ramp can't sneak the wheels back on.
void motorsStop() {
  g_jx = g_jy = 0;
  g_tgtL = g_tgtR = 0;
  g_curL = g_curR = 0;
  g_moving = false;
  applyWheel(true, 0);
  applyWheel(false, 0);
}

// Set where the wheels SHOULD end up; the loop ramps them there smoothly.
void setTargets(int left, int right) {
  g_tgtL = constrain(left,  -255, 255);
  g_tgtR = constrain(right, -255, 255);
  g_moving = (g_tgtL != 0 || g_tgtR != 0);
}

// Arcade mixing: turn the joystick (forward y + turn x) into left/right wheel
// targets, scaled by g_speed (DEFAULT_SPEED), with steering trim folded in.
void mixDrive() {
  int turn  = (g_jx * TURN_SPEED_SCALE) / 100;     // gentle, aim-able steering
  int left  = ((g_jy + turn) * g_speed) / 100;
  int right = ((g_jy - turn) * g_speed) / 100;
  // Trim eases ONE wheel a touch so the bot tracks straight (same idea as before).
  if (g_trim > 0)      right = (right * (100 - g_trim)) / 100;
  else if (g_trim < 0) left  = (left  * (100 + g_trim)) / 100;
  setTargets(left, right);
}

// Shape a raw axis (-100..100): dead-zone near centre, then an expo curve so a
// small push gives a small move while full deflection still reaches full speed.
//   out = (1-e)*x  +  e*x^3   (classic RC expo), all in integer math.
int shapeAxis(int v) {
  v = constrain(v, -100, 100);
  if (v > -JOY_DEADZONE && v < JOY_DEADZONE) return 0;
  long lin = ((long)(100 - JOY_EXPO) * v) / 100;
  long cub = ((long)JOY_EXPO * v * v * v) / 1000000L;   // x^3 scaled back to ±100
  return (int)(lin + cub);
}

void applyJoystick(int x, int y) {
  g_jx = shapeAxis(x);
  g_jy = shapeAxis(y);
  mixDrive();
}

// Move a value toward a goal by at most 'step' (the heart of the soft-start).
int stepToward(int cur, int goal, int step) {
  if (cur < goal) return min(cur + step, goal);
  if (cur > goal) return max(cur - step, goal);
  return cur;
}

// Called every loop tick: ease the wheels toward their targets and drive them.
void rampMotors() {
  g_curL = stepToward(g_curL, g_tgtL, ACCEL_STEP);
  g_curR = stepToward(g_curR, g_tgtR, ACCEL_STEP);
  applyWheel(true,  g_curL);
  applyWheel(false, g_curR);
}

// ---------------------------------------------------------------------------
//  DANCE  —  a quick "just for fun" freestyle. Bypasses ramping for snappy
//  moves and takes over the motors for ~4 s (loop() backs off while g_dancing).
// ---------------------------------------------------------------------------
void danceRoutine() {
  g_dancing = true;
  const int sp = 190;
  // 1) shimmy: snap left/right a few times
  for (int i = 0; i < 4; i++) {
    setLeft( 1, sp); setRight(-1, sp); delay(170);
    setLeft(-1, sp); setRight( 1, sp); delay(170);
  }
  // 2) victory spins
  setLeft( 1, sp); setRight(-1, sp); delay(750);
  setLeft(-1, sp); setRight( 1, sp); delay(750);
  // 3) bounce forward/back
  for (int i = 0; i < 3; i++) {
    setLeft( 1, sp); setRight( 1, sp); delay(150);
    setLeft(-1, sp); setRight(-1, sp); delay(150);
  }
  motorsStop();
  g_lastCmdMs = millis();        // don't let the failsafe fire right after
  g_dancing = false;
}

// ---------------------------------------------------------------------------
//  HEADLIGHT LED  (optional — only does anything when HAS_HEADLIGHT == 1)
// ---------------------------------------------------------------------------
void lightBegin() {
#if HAS_HEADLIGHT
  pinMode(LED_PIN, OUTPUT);
  digitalWrite(LED_PIN, LED_ACTIVE_HIGH ? LOW : HIGH);   // start OFF
#endif
}
void setLight(bool on) {
#if HAS_HEADLIGHT
  bool level = LED_ACTIVE_HIGH ? on : !on;
  digitalWrite(LED_PIN, level ? HIGH : LOW);
#endif
}

// ---------------------------------------------------------------------------
//  CAMERA
// ---------------------------------------------------------------------------
bool cameraBegin() {
  camera_config_t c = {};                      // zero everything first (important!)
  // The camera generates its clock (XCLK) with an LEDC unit. A plain camera
  // build puts it on channel0/timer0, but that has no other PWM. The drone
  // adds motor PWM, so we move the camera to the HIGHEST timer/channel (3 / 7).
  // The motor PWM below uses the Arduino LEDC auto-allocator, which hands out
  // timers/channels from the BOTTOM (0,1,2...). Keeping the camera up high means
  // the two never collide — which would otherwise break the video or the motor
  // speed. (XCLK works on any LEDC unit.)
  c.ledc_channel = LEDC_CHANNEL_7;
  c.ledc_timer   = LEDC_TIMER_3;
  c.pin_d0=Y2_GPIO_NUM; c.pin_d1=Y3_GPIO_NUM; c.pin_d2=Y4_GPIO_NUM; c.pin_d3=Y5_GPIO_NUM;
  c.pin_d4=Y6_GPIO_NUM; c.pin_d5=Y7_GPIO_NUM; c.pin_d6=Y8_GPIO_NUM; c.pin_d7=Y9_GPIO_NUM;
  c.pin_xclk=XCLK_GPIO_NUM; c.pin_pclk=PCLK_GPIO_NUM;
  c.pin_vsync=VSYNC_GPIO_NUM; c.pin_href=HREF_GPIO_NUM;
  c.pin_sccb_sda=SIOD_GPIO_NUM; c.pin_sccb_scl=SIOC_GPIO_NUM;
  c.pin_pwdn=PWDN_GPIO_NUM; c.pin_reset=RESET_GPIO_NUM;
  c.xclk_freq_hz=20000000;
  // Start at the BIGGEST size we'll ever use (HIRES_CEILING) so the PSRAM frame
  // buffers are allocated large enough; we immediately run it down to DRIVE size
  // below. This lets us shrink/grow at runtime without reallocating (the safe way).
  c.frame_size=HIRES_CEILING;
  c.pixel_format=PIXFORMAT_JPEG;
  c.grab_mode=CAMERA_GRAB_LATEST;              // always show the freshest frame
  c.fb_location=CAMERA_FB_IN_PSRAM;
  c.jpeg_quality=12;                           // 10=better/bigger, 20=worse/smaller
  c.fb_count=2;

  g_psram = psramFound();
  if (!g_psram) {                              // safety net if PSRAM is off
    c.frame_size=FRAMESIZE_QVGA; c.fb_location=CAMERA_FB_IN_DRAM; c.fb_count=1;
  }
  esp_err_t err = esp_camera_init(&c);
  if (err != ESP_OK) {
    Serial.printf("CAMERA INIT FAILED 0x%x — check camera_pins.h / PSRAM setting\n", err);
    return false;
  }
  sensor_t *s = esp_camera_sensor_get();
  if (s) {
    s->set_vflip(s, 1); s->set_hmirror(s, 0);  // flip if your image is upside down
    if (g_psram) { s->set_framesize(s, DRIVE_FRAMESIZE); g_curFrame = DRIVE_FRAMESIZE; }
    else         { g_curFrame = FRAMESIZE_QVGA; }   // no PSRAM -> stuck at the fallback
  }
  return true;
}

// Live image tuning — adjusted from the web controls without rebooting.
// brightness accepts -2..+2 (0 = normal); it just biases the picture.
void setBrightness(int v) {
  sensor_t *s = esp_camera_sensor_get();
  if (s) s->set_brightness(s, constrain(v, -2, 2));
}

// Signal strength (dBm) of the link. In AP mode that's how well the bot HEARS
// the phone; in STA mode it's how well the bot hears the router. ~ -45 strong,
// -75 getting weak, -85+ about to drop.
int linkRssi() {
#if WIFI_MODE == RECON_WIFI_AP
  wifi_sta_list_t list;
  if (esp_wifi_ap_get_sta_list(&list) == ESP_OK && list.num > 0)
    return list.sta[0].rssi;
  return 0;                                    // nobody connected
#else
  return WiFi.RSSI();
#endif
}

// Pick the biggest frame size the current signal can comfortably push, capped
// at HIRES_CEILING. Weak signal -> stay modest so the feed doesn't choke.
framesize_t chooseHiresFrame() {
  int r = linkRssi();
  framesize_t want;
  if      (r == 0)   want = DRIVE_FRAMESIZE;   // unknown / nobody connected
  else if (r >= -50) want = FRAMESIZE_UXGA;    // strong link
  else if (r >= -60) want = FRAMESIZE_SXGA;
  else if (r >= -70) want = FRAMESIZE_SVGA;
  else               want = DRIVE_FRAMESIZE;   // too weak for hi-res
  if ((int)want > (int)HIRES_CEILING) want = HIRES_CEILING;
  return want;
}

// HD button: on -> jump to the best size the link allows; off -> native feed.
void setHires(bool on) {
  g_hires = on;
  if (!g_psram) return;
  sensor_t *s = esp_camera_sensor_get();
  if (!s) return;
  framesize_t want = on ? chooseHiresFrame() : DRIVE_FRAMESIZE;
  if (want != g_curFrame && s->set_framesize(s, want) == 0) {
    g_curFrame = want;
    Serial.printf("Camera -> framesize %d (HD %s)\n", (int)want, on ? "on" : "off");
  }
}

// ---------------------------------------------------------------------------
//  HTTP: web app (port 80)
// ---------------------------------------------------------------------------
static esp_err_t index_handler(httpd_req_t *req) {
  httpd_resp_set_type(req, "text/html");
  httpd_resp_set_hdr(req, "Access-Control-Allow-Origin", "*");
  return httpd_resp_send(req, INDEX_HTML, HTTPD_RESP_USE_STRLEN);
}

// /control?joy=30,-80  &trim=-20 &bright=1 &light=1 &hires=1 &dance=1 &cmd=S
static esp_err_t control_handler(httpd_req_t *req) {
  char query[96] = {0};
  char val[24];
  bool tune = false;                            // trim changed this request?
  if (httpd_req_get_url_query_str(req, query, sizeof(query)) == ESP_OK) {
    if (httpd_query_key_value(query, "trim", val, sizeof(val)) == ESP_OK) {
      g_trim = constrain(atoi(val), -100, 100); tune = true;
    }
    if (httpd_query_key_value(query, "bright", val, sizeof(val)) == ESP_OK)
      setBrightness(atoi(val));
    if (httpd_query_key_value(query, "light", val, sizeof(val)) == ESP_OK)
      setLight(atoi(val) != 0);
    if (httpd_query_key_value(query, "hires", val, sizeof(val)) == ESP_OK)
      setHires(atoi(val) != 0);
    if (httpd_query_key_value(query, "joy", val, sizeof(val)) == ESP_OK) {
      int x = 0, y = 0; sscanf(val, "%d,%d", &x, &y);
      if (!g_dancing) applyJoystick(x, y);      // ignore steering mid-dance
    }
    if (httpd_query_key_value(query, "cmd", val, sizeof(val)) == ESP_OK) {
      if (val[0] == 'S') motorsStop();          // 'S' = stop, 'P' = ping (keep-alive)
    }
    if (httpd_query_key_value(query, "dance", val, sizeof(val)) == ESP_OK) {
      if (atoi(val) && !g_dancing) danceRoutine();
    }
  }
  // Trim moved while driving -> re-mix now so it takes effect live.
  if (tune && !g_dancing) mixDrive();
  g_lastCmdMs = millis();                        // heard from phone -> reset failsafe
  httpd_resp_set_hdr(req, "Access-Control-Allow-Origin", "*");
  return httpd_resp_send(req, "ok", 2);
}

// /stat -> plain-text RSSI in dBm, polled by the HUD for the signal meter.
static esp_err_t stat_handler(httpd_req_t *req) {
  char b[16];
  int n = snprintf(b, sizeof(b), "%d", linkRssi());
  httpd_resp_set_hdr(req, "Access-Control-Allow-Origin", "*");
  return httpd_resp_send(req, b, n);
}

// ---------------------------------------------------------------------------
//  HTTP: MJPEG video stream (port 81)
// ---------------------------------------------------------------------------
#define PART_BOUNDARY "frameboundary"
static const char *STREAM_CT  = "multipart/x-mixed-replace;boundary=" PART_BOUNDARY;
static const char *STREAM_BND = "\r\n--" PART_BOUNDARY "\r\n";
static const char *STREAM_PART= "Content-Type: image/jpeg\r\nContent-Length: %u\r\n\r\n";

static esp_err_t stream_handler(httpd_req_t *req) {
  esp_err_t res = httpd_resp_set_type(req, STREAM_CT);
  if (res != ESP_OK) return res;
  httpd_resp_set_hdr(req, "Access-Control-Allow-Origin", "*");
  char part[64];
  while (true) {
    camera_fb_t *fb = esp_camera_fb_get();
    if (!fb) { res = ESP_FAIL; break; }
    size_t hlen = snprintf(part, sizeof(part), STREAM_PART, fb->len);
    if ((res = httpd_resp_send_chunk(req, STREAM_BND, strlen(STREAM_BND))) != ESP_OK) { esp_camera_fb_return(fb); break; }
    if ((res = httpd_resp_send_chunk(req, part, hlen)) != ESP_OK)                      { esp_camera_fb_return(fb); break; }
    if ((res = httpd_resp_send_chunk(req, (const char*)fb->buf, fb->len)) != ESP_OK)   { esp_camera_fb_return(fb); break; }
    esp_camera_fb_return(fb);
  }
  return res;
}

void startServers() {
  httpd_config_t cfg = HTTPD_DEFAULT_CONFIG();
  cfg.server_port = 80;
  cfg.ctrl_port   = 32080;
  cfg.lru_purge_enable = true;
  httpd_uri_t index_uri   = { "/",        HTTP_GET, index_handler,   NULL };
  httpd_uri_t control_uri = { "/control", HTTP_GET, control_handler, NULL };
  httpd_uri_t stat_uri    = { "/stat",    HTTP_GET, stat_handler,    NULL };
  if (httpd_start(&control_httpd, &cfg) == ESP_OK) {
    httpd_register_uri_handler(control_httpd, &index_uri);
    httpd_register_uri_handler(control_httpd, &control_uri);
    httpd_register_uri_handler(control_httpd, &stat_uri);
  }
  cfg.server_port = 81;
  cfg.ctrl_port   = 32081;
  httpd_uri_t stream_uri  = { "/stream", HTTP_GET, stream_handler, NULL };
  if (httpd_start(&stream_httpd, &cfg) == ESP_OK) {
    httpd_register_uri_handler(stream_httpd, &stream_uri);
  }
}

// ---------------------------------------------------------------------------
//  SETUP / LOOP
// ---------------------------------------------------------------------------
void setup() {
  Serial.begin(115200);
  delay(300);
  Serial.println("\nReconBot booting...");

  motorsBegin();  motorsStop();
  lightBegin();

#if USE_IMU
  Wire.begin(IMU_SDA, IMU_SCL);
#endif

  if (!cameraBegin()) {
    Serial.println("Continuing without camera — driving will still work.");
  }

#if WIFI_MODE == RECON_WIFI_AP
  WiFi.mode(WIFI_AP);
  // softAP(ssid, pass, channel, hidden, max_conn). hidden=1 keeps the SSID off
  // the air so it never appears in a phone's WiFi list (see AP_HIDDEN in config.h).
  WiFi.softAP(AP_SSID, AP_PASS, AP_CHANNEL, AP_HIDDEN);
  Serial.printf("AP up%s. Join WiFi '%s', then open  http://192.168.4.1\n",
                AP_HIDDEN ? " (HIDDEN — add the network manually on your phone)" : "",
                AP_SSID);
#else
  WiFi.mode(WIFI_STA);
  WiFi.begin(STA_SSID, STA_PASS);
  Serial.print("Joining home WiFi");
  for (int i = 0; i < 40 && WiFi.status() != WL_CONNECTED; i++) { delay(250); Serial.print("."); }
  Serial.println();
  if (WiFi.status() == WL_CONNECTED)
    Serial.printf("Connected. Open  http://%s\n", WiFi.localIP().toString().c_str());
  else
    Serial.println("WiFi failed — check STA_SSID/STA_PASS in config.h");
#endif

  startServers();
  g_lastCmdMs = millis();
  Serial.println("Ready. Drive safe.");
}

void loop() {
  // While the DANCE routine runs it owns the motors directly, so back off.
  if (!g_dancing) {
    // FAILSAFE: if the phone went quiet, stop the wheels.
    if (g_moving && (millis() - g_lastCmdMs > FAILSAFE_MS)) {
      motorsStop();
      Serial.println("Failsafe: no commands -> motors stopped.");
    }

    // Soft-start: ease the wheels toward their targets every tick.
    rampMotors();
  }
  delay(20);
}

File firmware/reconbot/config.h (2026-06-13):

// ===========================================================================
//  config.h  —  ReconBot central configuration
// ---------------------------------------------------------------------------
//  This is the ONE file you edit to change WiFi, pins, and tuning.
//  Everything in the sketch reads from here, so you never have to hunt
//  through the code to change a pin number.
// ===========================================================================
#pragma once

// ---------------------------------------------------------------------------
//  1) WiFi mode
// ---------------------------------------------------------------------------
//  AP   = the bot makes its OWN WiFi hotspot. Your iPhone joins it directly.
//         Works anywhere, no home router needed. RECOMMENDED for a drone.
//  STA  = the bot joins your home WiFi. You browse to the IP it prints on the
//         serial monitor. Use this only if you want it on your home network.
//
//  Pick ONE by setting WIFI_MODE below.
//  NOTE: these are named RECON_* (not WIFI_MODE_AP/STA) on purpose — the ESP32
//  WiFi library already owns WIFI_MODE_AP / WIFI_MODE_STA as enum values, and
//  redefining them here breaks WiFi.mode(). Don't rename these back.
#define RECON_WIFI_AP    0
#define RECON_WIFI_STA   1

#define WIFI_MODE   RECON_WIFI_AP     // <-- change to RECON_WIFI_STA to join home WiFi

// --- Access-Point mode settings (the bot's own hotspot) -------------------
#define AP_SSID     "ReconBot"         // the WiFi name your phone will see
#define AP_PASS     "changeme123"      // 8+ characters. CHANGE THIS before you build!
#define AP_CHANNEL  1                 // 1, 6, or 11 are the cleanest channels
#define AP_HIDDEN   1                 // 1 = hidden SSID (won't show in WiFi lists),
                                      // 0 = visible. When hidden, add the network
                                      // MANUALLY on your phone (name = AP_SSID above).
// The bot is always reachable at  http://192.168.4.1  in AP mode.

// --- Station mode settings (join your home WiFi) --------------------------
#define STA_SSID    "YourHomeWiFi"
#define STA_PASS    "YourWiFiPassword"

// ---------------------------------------------------------------------------
//  2) Motor driver pins  (L298N)
// ---------------------------------------------------------------------------
//  Chosen for the FORIOT ESP32-S3-CAM (N16R8). They avoid the camera pins
//  (4-18, confirmed for this FORIOT board), the octal flash+PSRAM pins
//  (26-37), the USB pins (19,20), the serial/CH340 pins (43,44), and the
//  boot/strapping pins (0,3,45,46).
//
//  NOTE: GPIO 38/39/40 are the on-board microSD slot pins (1-bit SDIO). We
//  reuse them here because the drone doesn't use the SD card. >>> Leave the
//  microSD slot EMPTY <<< or the card and the motors will fight over the pins.
//
//  If any pin isn't broken out on a header pad on your board, pick another
//  free pin (good spares: 21, 47, 48, 1, 2) and change it HERE only. Check
//  your board's silkscreen / pinout image to see which pads are broken out.
//
//  Motor A = LEFT wheel, Motor B = RIGHT wheel  (swap later if needed).
#define MOTOR_A_IN1   42     // direction pin 1 (Motor A / left)
#define MOTOR_A_IN2   41     // direction pin 2 (Motor A / left)
#define MOTOR_A_PWM   40     // ENA - speed (PWM) for Motor A / left  (SD D0 pad)
#define MOTOR_B_IN3   39     // direction pin 1 (Motor B / right)     (SD CLK pad)
#define MOTOR_B_IN4   38     // direction pin 2 (Motor B / right)     (SD CMD pad)
#define MOTOR_B_PWM   47     // ENB - speed (PWM) for Motor B / right

// If the bot drives BACKWARD when you press forward, flip these to true.
#define INVERT_LEFT   false
#define INVERT_RIGHT  false

// ---------------------------------------------------------------------------
//  3) Optional: MPU-6050 IMU (tilt read-out shown on the web HUD)
// ---------------------------------------------------------------------------
//  Leave USE_IMU 0 for the first build. Turn on later as a fun add-on.
#define USE_IMU       0
#define IMU_SDA       1
#define IMU_SCL       2

// ---------------------------------------------------------------------------
//  4) Driving feel / safety
// ---------------------------------------------------------------------------
#define PWM_FREQ      1000   // motor PWM frequency in Hz (1 kHz is quiet+smooth)
#define PWM_RES_BITS  8      // 8-bit -> speed values 0..255
#define DEFAULT_SPEED 200    // TOP speed (0-255): full joystick push = this duty.
                             // (There's no speed slider anymore — the stick IS
                             // the throttle. Lower this if it's still too quick.)
#define TURN_SPEED_SCALE 50  // steering sensitivity: how much the joystick's
                             // left/right push affects the wheels (%). Lower =
                             // gentler, easier-to-aim turns; higher = sharper.
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

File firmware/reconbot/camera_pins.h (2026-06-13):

// ===========================================================================
//  camera_pins.h  —  Camera pin map for the ESP32-S3-CAM
// ---------------------------------------------------------------------------
//  These are the pins that connect the ESP32-S3 to the on-board camera.
//
//  >>> CONFIRMED <<<  This map is taken from the FORIOT ESP32-S3-CAM silkscreen
//  pinout and has been verified on real hardware, so there's no need to guess.
//  If you use a different ESP32-S3-CAM board, double-check these against its
//  own pinout before flashing.
// ===========================================================================
#pragma once

#define PWDN_GPIO_NUM    -1   // not connected on this board
#define RESET_GPIO_NUM   -1   // not connected on this board
#define XCLK_GPIO_NUM    15
#define SIOD_GPIO_NUM     4   // camera I2C data (SCCB SDA)
#define SIOC_GPIO_NUM     5   // camera I2C clock (SCCB SCL)

#define Y9_GPIO_NUM      16
#define Y8_GPIO_NUM      17
#define Y7_GPIO_NUM      18
#define Y6_GPIO_NUM      12
#define Y5_GPIO_NUM      10
#define Y4_GPIO_NUM       8
#define Y3_GPIO_NUM       9
#define Y2_GPIO_NUM      11

#define VSYNC_GPIO_NUM    6
#define HREF_GPIO_NUM     7
#define PCLK_GPIO_NUM    13

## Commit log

2026-06-13 Initial public release: ReconBot v1
    [drone-lid.stl, drone_chassis.stl]
2026-06-13 Add build photos (assembled drone + internals); show in README
2026-06-13 Remove camera tilt/servo; fix stale speed-slider references
    [config.h, reconbot.ino]
